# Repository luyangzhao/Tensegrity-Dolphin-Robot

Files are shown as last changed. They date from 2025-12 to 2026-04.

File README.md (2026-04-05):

# Tensegrity Dolphin Robot

Open-source design files for an **untethered bio-inspired robotic dolphin** with a **tensegrity-based, multi-flexibility tail** for efficient aquatic locomotion. This repository provides the mechanical, electronic, and software resources needed to understand, reproduce, and extend the robotic system presented in our RoboSoft 2025 paper.

---

### **🎥 Dolphin Demonstration Video**  
Please watch the robotic dolphin in action.

Dolphin Video (https://www.youtube.com/watch?v=avUUYTJ178g)

---
## Overview

The Tensegrity Dolphin Robot features a **hybrid rigid–soft architecture**:
- A rigid, waterproof head module housing electronics, actuation, and power.
- A flexible tensegrity tail skeleton enabling distributed compliance.
- A molded silicone tail skin provides smooth hydrodynamic surfaces.
- Modular connectors allow rapid tail replacement and reconfiguration.

By varying the internal tail skeleton geometry, the robot can achieve different flexibility profiles and swimming performance, enabling systematic studies of morphology–locomotion trade-offs.

---

## Repository Structure

```
Tensegrity-Dolphin-Robot/
├── CAD/          # Mechanical design files (head, tail, molds, connectors)
├── PCB/          # Electronics design files
├── Firmware/     # Embedded firmware (ESP32)
├── Software/     # Control code
├── assets/       # Images and media
├── LICENSE 
└── README.md
```
---

## Reference

This repository accompanies the paper:

 Luyang Zhao, Yitao Jiang, Chun-Yi She, Mingi Jeong, Haibo Dong, Alberto Quattrini Li, Muhao Chen, and Devin Balkcom., 2025. An Untethered Bioinspired Robotic Tensegrity Dolphin with Multi-Flexibility Design for Aquatic Locomotion. In *2025 IEEE 8th International Conference on Soft Robotics (RoboSoft)* (pp. 1-7). IEEE

Paper link:  
https://ieeexplore.ieee.org/document/11020959

If you use this repository in your research, please cite the above paper.

---

## Fabrication and Reproduction

This repository provides the design files and code necessary to reproduce the robotic system at a system level. Detailed fabrication procedures, material choices, and experimental setup are described in the accompanying paper.

In brief, reproduction involves:
1. Fabrication of the rigid head components and tensegrity tail skeleton
2. Molding of the silicone tail using the provided mold designs
3. Assembly of the actuation system and connectors
4. Integration of electronics and firmware
5. Waterproofing, tuning, and aquatic testing

Readers are encouraged to refer to the paper for detailed descriptions of materials, dimensions, and experimental protocols.

---

## Waterproofing Considerations

Waterproofing is a critical aspect of the robotic system and requires careful mechanical and material design. Based on our implementation, the key considerations include:

1. **Shaft sealing**  
   Proper sealing of rotating shafts is the primary and most critical waterproofing measure. Inadequate shaft sealing cannot be compensated for by external coatings or adhesives.

2. **Silicone-based sealing and bonding**  
   Silicone glue and sealants are used to seal housing interfaces, forming the system-level waterproof barrier.

3. **Water-resistant fabrication materials**  
   Waterproof or water-resistant printing materials (e.g., resin-based prints) help reduce water ingress but should be considered a supporting measure rather than a standalone solution.

Successful waterproofing requires the **combined use** of all three approaches rather than reliance on any single method.

---

## 📬 Contact

For questions, collaboration, or reproducibility assistance:

📧 **Luyang Zhao** — [luyangz@clemson.edu](mailto:luyangz@clemson.edu)  
📧 **Yitao Jiang** — [yitao.jiang.gr@dartmouth.edu](mailto:yitao.jiang.gr@dartmouth.edu)

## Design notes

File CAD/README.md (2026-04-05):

# CAD – Mechanical Design Files

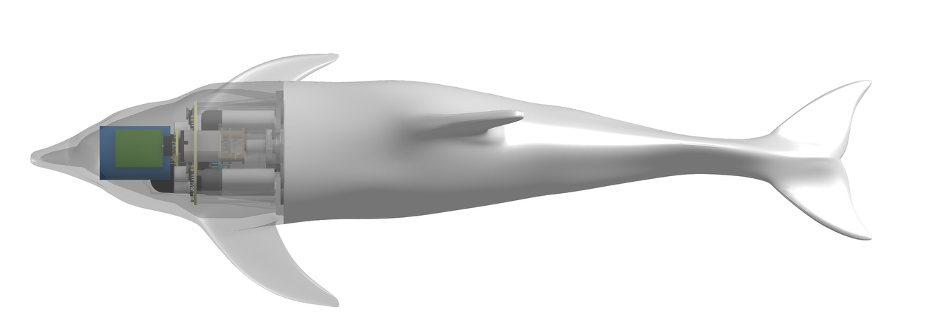
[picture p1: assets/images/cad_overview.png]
Mechanical overview of the dolphin robot showing the rigid head and tensegrity tail backbone.


This directory contains all mechanical CAD files for the **Tensegrity Dolphin Robot**, including rigid structural components, flexible tail structures, silicone molding tools, and modular connectors. The mechanical design follows a **hybrid rigid–soft architecture**:
- A rigid, waterproof head houses all electronics, actuation, and power components.
- A compliant tail enables efficient aquatic locomotion through distributed flexibility.
- Modular connectors allow rapid assembly, disassembly, and tail replacement.

---

## Directory Structure

```
CAD/
├── head/
├── tensegrity_tail/
├── silicone_tail_molding/
├── connectors/
```

---

## Subdirectories

### 1. `head/`
Rigid structural components form the waterproof head enclosure, includes:
- Outer shell and internal mounting frames  
- Motor, pulley, and cable-routing mounts  
- Battery, PCB, and wireless charging coil fixtures  
- Sealing interfaces and fastening features  

These components are designed to be fabricated via **3D printing or CNC machining** and assembled to form a pressure-resistant electronics compartment.

---

### 2. `tensegrity_tail/`
Internal flexible backbone defining the tail’s deformation behavior, includes:
- Fish-bone–inspired rigid ribs  
- Interconnecting elements and spacers  
- Cable routing guides and anchor points  

This structure provides **distributed compliance** and enables smooth bending under cable-driven actuation.

---

### 3. `silicone_tail_molding/`
Mold designs used to fabricate the soft silicone tail skin, includes:
- Multi-part molds for the outer tail geometry  
- Internal buoyancy chamber molds  
- Alignment, venting, and demolding features  

The molded silicone tail provides continuous curvature, tunable stiffness, and passive compliance for efficient swimming.

---

### 4. `connectors/`
Modular interfaces between the rigid head and the flexible tail, includes:
- Magnetic coupling components  
- Mechanical alignment and load-transfer features  

These connectors enable **rapid tail replacement and maintenance** without disassembling the head module.

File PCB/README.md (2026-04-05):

# **PCB Design** 

## 🔗 Access the PCB Design  
The full **schematic, layout, and fabrication files** for the PCB are available in this directory. Please use EasyEDA (LCEDA) to open **ProPrj_Dolphin 3D.epro** for the source. You can also directly use the Gerber, BOM, and CPL files to produce the board.

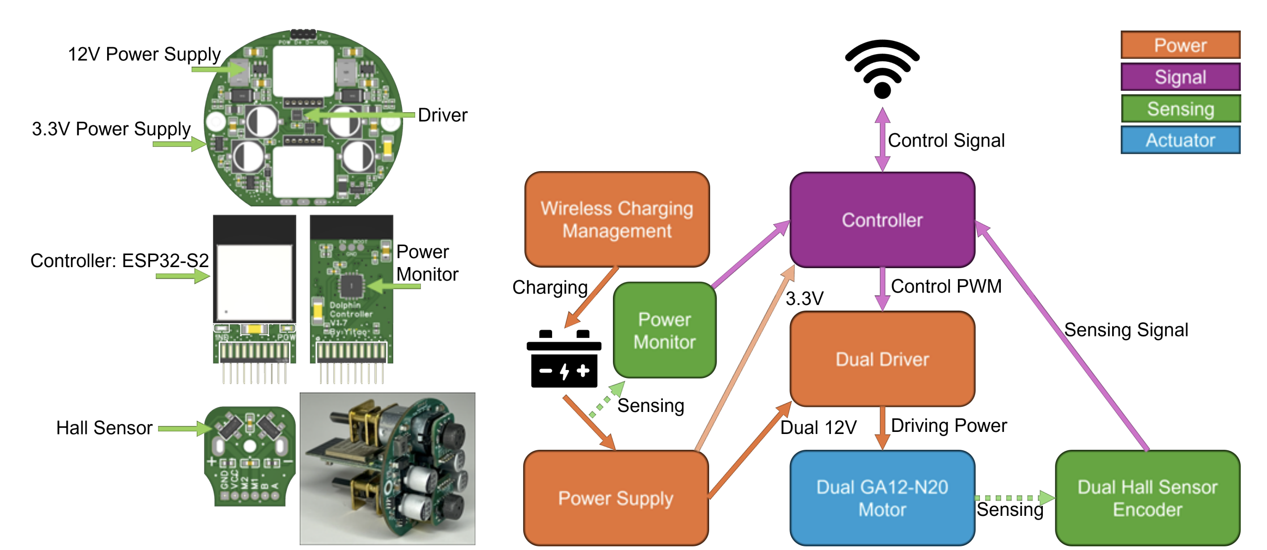
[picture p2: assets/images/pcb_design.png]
SoftSnap 3-in-1 Motor Module PCB
  

## 🛠️ Manufacture of this PCB
Recommend using **JLCPCB for production**.

Manufacturing parameters:  
1️⃣ **Main Board** – Use a 1 mm 4-layer board. Others can be default.  
2️⃣ **Controller** – Use a 0.8 mm 4-layer board. Others can be default.  
3️⃣ **Encoder** – Use a 1 mm 2-layer board. Others can be default.  

## 🛍️ Other parts for assembly the robot
You will need these components to build this Dolphin robot. If the link has expired, you can find an equivalent.  

1️⃣ **1.27x10x2p Male Pin Connector** – You need to solder the connector vertically to the Main Board as shown in the `pcb_design` figure.  
2️⃣ **702025 Li-Po Battery 250 mAh** – You need 2 batteries for one robot. [Taobao Link](https://item.taobao.com/item.htm?_u=fb6lncqb37e&id=707886319580&skuId=5171695959474)  
3️⃣ **5F/5.5V 21x10x27mm 16mm-pin Capacitor** – A smaller capacitor may also work, but this is perfectly fit in size. [Tmall Link](https://detail.tmall.com/item.htm?_u=fb6lncq1c6a&id=641504092942&skuId=4790094927334)  
4️⃣ **HK015T.1 Power Switch Chip** – This part is not in the JLCPCB library, so you may need to purchase it yourself. [Taobao Link](https://item.taobao.com/item.htm?_u=fb6lncq935a&id=675015766647&skuId=4893699864706)  
5️⃣ **Tactile switch 4x4x3.5** – This part will be used to control the power of the robot. [Taobao Link](https://item.taobao.com/item.htm?_u=fb6lncq47bf&id=578313422043&skuId=3994993738973)  
6️⃣ **5W receiving module (square 23x30 coil) + 10W transmitting module** – This part is for wireless charging. [Taobao Link](https://item.taobao.com/item.htm?_u=fb6lncq9349&id=681481042391&skuId=5051612254394)  
7️⃣ **Shaft Seal 5x13x5** – This part is for wireless charging. [Taobao Link](https://item.taobao.com/item.htm?_u=fb6lncq98e2&id=652255362545&skuId=4713539808324)  
8️⃣ **Encoder Magnet** – We are using a Radial 6-pole. If you can't find it, other poles may also work. [Taobao Link](https://item.taobao.com/item.htm?_u=fb6lncq2191&id=539394627100)  
9️⃣ **GA12-N20 Motor with rear shaft** – We are using 1:150 gear ratio, 12V, 200RPM (no load). Since we need a lot of this motor, we ordered it from this vendor. You may find other equivalents for a small quantity. [Taobao Link](https://shop108869903.taobao.com/?spm=pc_detail.30350276.shop_block.dshopinfo.2fe07dd6G8NZ3C)  
🔟 **M1.7*6 Self-Tapping Screws** – Use this screw to connect Main Board with 3D printed inner structure. [Tmall Link](https://detail.tmall.com/item.htm?_u=fb6lncqd00d&id=601243288882&skuId=5653049345641)  
1️⃣1️⃣ **M1.6*3 Screws** – Use this screw to connect GA12-N20 Motor with 3D printed inner structure. [Tmall Link](https://detail.tmall.com/item.htm?_u=fb6lncqb704&id=601243200968&skuId=5945136077418)  
1️⃣2️⃣ Wires are needed for assembly, recommend 22AWG or thicker for the power cord. The switch wire can be thin.

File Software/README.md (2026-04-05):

# Software – High-Level Control

This directory contains **high-level control and interaction software** for the **Tensegrity Dolphin Robot**. The software runs on an external computer and communicates wirelessly with the onboard firmware to command tail actuation and support basic experimentation.

---

## Contents

- `Control_Program_Dolphin.ipynb`  
  A Jupyter Notebook providing a high-level control interface for commanding the two tail motors to generate **undulatory swimming motions**.

The notebook is intended for demonstration, testing, and exploratory control, rather than optimized autonomous operation.

---

## Notes

- The software communicates with the embedded firmware provided in `firmware/`.
- Control parameters and motion patterns may require tuning depending on the tail configuration and materials.

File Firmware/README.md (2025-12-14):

# Firmware – Embedded Control

This directory contains the **embedded firmware** used to operate the **Tensegrity Dolphin Robot**.

The firmware runs on an onboard microcontroller and is responsible for low-level motor actuation, communication, and system management for untethered aquatic operation.

---

## Overview

The firmware supports:
- Cable-driven motor control for tail actuation
- Wireless communication for command and monitoring
- Basic system management for untethered operation

The firmware is designed to interface directly with the PCB referenced in `PCB/` and the mechanical components defined in `CAD/`.

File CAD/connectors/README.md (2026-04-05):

# Connectors – Tail–Head Interface

This directory contains CAD files for the **connector components** that interface the tensegrity tail skeleton with the rigid head module.

## Files

- `Tail_Connector.stl`  
  Connector component used to mechanically interface the tail skeleton with the head module. This part provides alignment and load transfer between the rigid head and the flexible tail.

## Notes

- The connector is compatible with all tail skeleton variants.

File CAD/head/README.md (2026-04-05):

- `Head.stl`  
  Outer head shell forming the hydrodynamic exterior and primary waterproof barrier. This part should be printed using **resin or other waterproof materials**.

- `Head_Inner.stl`  
  Internal structural frame for mounting motors, magnets, batteries, and electronics. This part does not require waterproof material and can be fabricated using standard 3D printing materials.

- `Winch.stl`  
  Winch component used to wind and release the actuation string driven by the motor.

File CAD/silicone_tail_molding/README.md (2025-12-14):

# Silicone Tail Molding – CAD Files

This directory contains CAD files related to the **fabrication of the soft silicone tail**, including molding tools and reference geometry.

---

## Files Overview

### Reference Geometry (Not for Printing)

- `silicone tail final shape (no need to print).stl`  
  Final outer geometry of the silicone tail after molding.  
  This file is provided **for reference and visualization only** and **should not be printed**.  
  It represents the expected final shape of the molded silicone tail.

---

### Molding Components (Used for Fabrication)

The following files are used to fabricate the silicone tail via molding:

- `Mold Outer A.stl`  
  One half of the outer mold defining the external surface of the silicone tail.

- `Mold Outer B.stl`  
  The complementary half of the outer mold.  
  Together with `Mold Outer A.stl`, it forms the complete outer mold cavity.

- `Mold Inner.stl`  
  Inner mold insert used to form internal features of the silicone tail, such as internal cavities or buoyancy chambers.

---

## Notes

- Only the **mold components and inserts** should be fabricated (e.g., via 3D printing).
- The final silicone tail is produced by casting silicone into the assembled mold.

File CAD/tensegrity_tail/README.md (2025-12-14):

# Tensegrity Tail – Skeleton Variants

This directory contains **six tensegrity tail skeleton variants** corresponding to the designs evaluated in the paper.  
All variants share the same overall geometry and interface to the head module, but differ in **rib height ratio (h₁:h₂)** and **structural thickness ratio**, resulting in different tail flexibility and swimming performance.

---

## Skeleton Variants

The following STL files correspond to the skeleton types reported in the paper:

| Skeleton Type | h₁:h₂ | Thickness Ratio | STL File |
|---|---|---|---|
| Type 1 | 1:1 | 1:1 | `Type1_h1-1_thick1-1.stl` |
| Type 2 | 1:1 | 2:1 | `Type2_h1-1_thick2-1.stl` |
| Type 3 | 1:1 | 3:1 | `Type3_h1-1_thick3-1.stl` |
| Type 4 | 1:2 | 1:1 | `Type4_h1-2_thick1-1.stl` |
| Type 5 | 1:2 | 2:1 | `Type5_h1-2_thick2-1.stl` |
| Type 6 | 1:2 | 3:1 | `Type6_h1-2_thick3-1.stl` |

---

## Usage Notes

- All skeleton variants are **mechanically compatible** with the same head module, connectors, and actuation system.
- Skeletons can be swapped without modifying electronics or control software.
- Changing the skeleton alters tail flexibility, bending amplitude, swimming speed, and energy efficiency.

Type 4 (`Type4_h1-2_thick1-1.stl`) has fastest swimming speed and lowest cost of transport.

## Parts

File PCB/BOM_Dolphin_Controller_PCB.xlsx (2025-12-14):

No. | Quantity | Device | Designator | Footprint | Value | Manufacturer Part | Manufacturer | Supplier Part | Supplier | JLCPCB Part Class
1 | 2 | CL31A107MQHNNNE | C6,C19 | C1206 | 100uF | CL31A107MQHNNNE | SAMSUNG(三星) | C15008 | LCSC | Basic Part
2 | 1 | CL21A226MAQNNNE | C7 | C0805 | 22uF | CL21A226MAQNNNE | SAMSUNG(三星) | C45783 | LCSC | Basic Part
3 | 2 | CL05B104KB54PNC | C8,C17 | C0402 | 100nF | CL05B104KB54PNC | SAMSUNG(三星) | C307331 | LCSC | Basic Part
4 | 2 | CL05A105KA5NQNC | C16,C18 | C0402 | 1uF | CL05A105KA5NQNC | SAMSUNG(三星) | C52923 | LCSC | Basic Part
5 | 1 | KH-1.27PH180-2X10P-L7.2 | H1 | KH-1.27PH180-2X10P-L7.2 夹板 |  | KH-1.27PH180-2X10P-L7.2 | kinghelm(金航标) | C2938414 | LCSC | 扩展库
6 | 1 | KT-0603R | LED1 | LED0603-RD |  | KT-0603R | KENTO | C2286 | LCSC | Basic Part
7 | 1 | KT-0603W | LED2 | LED0603-RD |  | KT-0603W | KENTO | C2290 | LCSC | Basic Part
8 | 3 | 0402WGF1001TCE | R3,R8,R9 | R0402 | 1kΩ | 0402WGF1001TCE | UNI-ROYAL(厚声) | C11702 | LCSC | Basic Part
9 | 2 | Test-Point | TP1,TP2 | test-point-0.5mm
10 | 1 | ESP32-S2-MINI-2-N4 | U1 | WIFI-SMD_ESP32-MINI-1-N4 | 2.4GHz | ESP32-S2-MINI-2-N4 | ESPRESSIF(乐鑫) | C3013906 | LCSC | Extended Part
11 | 1 | INA3221AIRGVR | U7 | QFN-16_L4.0-W4.0-P0.65-TL-EP2.2 |  | INA3221AIRGVR | TI(德州仪器) | C181255 | LCSC | 扩展库

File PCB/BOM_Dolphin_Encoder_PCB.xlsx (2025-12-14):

No. | Quantity | Device | Designator | Footprint | Value | Manufacturer Part | Manufacturer | Supplier Part | Supplier | JLCPCB Part Class
1 | 1 | CL05A105KA5NQNC | C1 | C0402 | 1uF | CL05A105KA5NQNC | SAMSUNG(三星) | C52923 | LCSC | Basic Part
2 | 1 | CL05B104KB54PNC | C2 | C0402 | 100nF | CL05B104KB54PNC | SAMSUNG(三星) | C307331 | LCSC | Basic Part
3 | 2 | 0402WGF2201TCE | R1,R2 | R0402 | 2.2kΩ | 0402WGF2201TCE | UNI-ROYAL(厚声) | C25879 | LCSC | Basic Part
4 | 2 | DRV5013ADQDBZR | U1,U2 | SOT-23-3_L2.9-W1.3-P1.90-LS2.4-BR |  | DRV5013ADQDBZR | TI(德州仪器) | C575585 | LCSC | Extended Part
5 | 1 | PZ127-1-06-Z | U3 | HDR-TH_6P-P1.27-V-M |  | PZ127-1-06-Z | HCTL(华灿天禄) | C5372829 | LCSC | 扩展库

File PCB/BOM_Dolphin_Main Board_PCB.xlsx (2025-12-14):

No. | Quantity | Device | Designator | Footprint | Value | Manufacturer Part | Manufacturer | Supplier Part | Supplier | JLCPCB Part Class
1 | 4 | 126RV0010 | C1,C17,C18,C19 | CAP-SMD_BD6.3-L6.6-W6.6-FD | 470uF | 126RV0010 | KNSCHA(科尼盛) | C5354997 | LCSC | Extended Part
2 | 2 | CL05A105KA5NQNC | C2,C3 | C0402 | 1uF | CL05A105KA5NQNC | SAMSUNG(三星) | C52923 | LCSC | Basic Part
3 | 5 | CL05B104KB54PNC | C9,C10,C38,C43,C44 | C0402 | 100nF | CL05B104KB54PNC | SAMSUNG(三星) | C307331 | LCSC | Basic Part
4 | 1 | CL31A107MQHNNNE | C29 | C1206 | 100uF | CL31A107MQHNNNE | SAMSUNG(三星) | C15008 | LCSC | Basic Part
5 | 6 | CL21A226MAQNNNE | C31,C35,C39,C40,C41,C42 | C0805 | 22uF | CL21A226MAQNNNE | SAMSUNG(三星) | C45783 | LCSC | Basic Part
6 | 1 | CL05A106MQ5NUNC | C45 | C0402 | 10uF | CL05A106MQ5NUNC | SAMSUNG(三星) | C15525 | LCSC | Basic Part
7 | 2 | PM127-1-06-4.3-G0 | CN2,CN3 | HDR-TH_6P-P1.27-V-F |  | PM127-1-06-4.3-G0 | HCTL(华灿天禄) | C5447364 | LCSC | Extended Part
8 | 2 | SS54_C22452 | D4,D5 | SMA_L4.4-W2.8-LS5.4-R-RD |  | SS54 | MDD(辰达半导体) | C22452 | LCSC | Basic Part
9 | 1 | 1N5819WS_C191023 | D6 | SOD-323_L1.8-W1.3-LS2.5-RD |  | 1N5819WS | Hottech(合科泰) | C191023 | LCSC | 基础库
10 | 1 | PZ127V-11-04-H25 | H3 | HDR-TH_4P-P1.27-V-M |  | PZ127V-11-04-H25 | XFCN(兴飞) | C962328 | LCSC | 扩展库
11 | 2 | SMNR4030-6R8MT | L2,L3 | IND-SMD_L4.0-W4.0_FNR4012S | 6.8uH | SMNR4030-6R8MT | SXN(顺翔诺) | C5307592 | LCSC | Extended Part
12 | 1 | AO3401A_C15127 | Q1 | SOT-23_L2.9-W1.3-P1.90-LS2.4-BR |  | AO3401A | AOS | C15127 | LCSC | 基础库
13 | 3 | 0402WGF2003TCE | R12,R33,R34 | R0402 | 200kΩ | 0402WGF2003TCE | UNI-ROYAL(厚声) | C25764 | LCSC | Basic Part
14 | 1 | 0402WGF1001TCE | R15 | R0402 | 1kΩ | 0402WGF1001TCE | UNI-ROYAL(厚声) | C11702 | LCSC | 基础库
15 | 2 | RL0805FR-070R04L | R17,R27 | R0805 | 40mΩ | RL0805FR-070R04L | YAGEO(国巨) | C326963 | LCSC | 扩展库
16 | 6 | 0402WGF100KTCE | R21,R22,R28,R29,R30,R31 | R0402 | 1Ω | 0402WGF100KTCE | UNI-ROYAL(厚声) | C25086 | LCSC | Extended Part
17 | 2 | 0402WGF1743TCE | R23,R25 | R0402 | 174kΩ | 0402WGF1743TCE | UNI-ROYAL(厚声) | C26994 | LCSC | Extended Part
18 | 2 | 0402WGF1002TCE | R24,R26 | R0402 | 10kΩ | 0402WGF1002TCE | UNI-ROYAL(厚声) | C25744 | LCSC | Basic Part
19 | 1 | HoLR1206-1W-20mR-1%-75ppm | R32 | R1206 | 20mΩ | HoLR1206-1W-20mR-1%-75ppm | Milliohm(毫欧) | C601099 | LCSC | 扩展库
20 | 1 | RT9013-33GB | U1 | SOT-23-5_L3.0-W1.7-P0.95-LS2.8-BL |  | RT9013-33GB | RICHTEK(立锜) | C47773 | LCSC | Extended Part
21 | 2 | DRV8837DSGR | U4,U5 | WSON-8_L2.0-W2.0-P0.50-TL-EP |  | DRV8837DSGR | TI(德州仪器) | C39159 | LCSC | Extended Part
22 | 2 | MT3608L | U8,U9 | SOT-23-6_L2.9-W1.7-P0.95-LS2.8-BL |  | MT3608L | 西安航天民芯 | C2932326 | LCSC | Extended Part
23 | 1 | KH-1.27FH-2X10P-H4.3-SMT | U10 | CONN-SMD_20P-P1.27_KINGHELM_KH-1.27FH-2X10P-H4.3-SMT |  | KH-1.27FH-2X10P-H4.3-SMT | kinghelm(金航标) | C2938399 | LCSC | 扩展库
24 | 1 | HOKEC 0339D | U13 | SOT-23-6_L2.9-W1.6-P0.95-LS2.8-BL

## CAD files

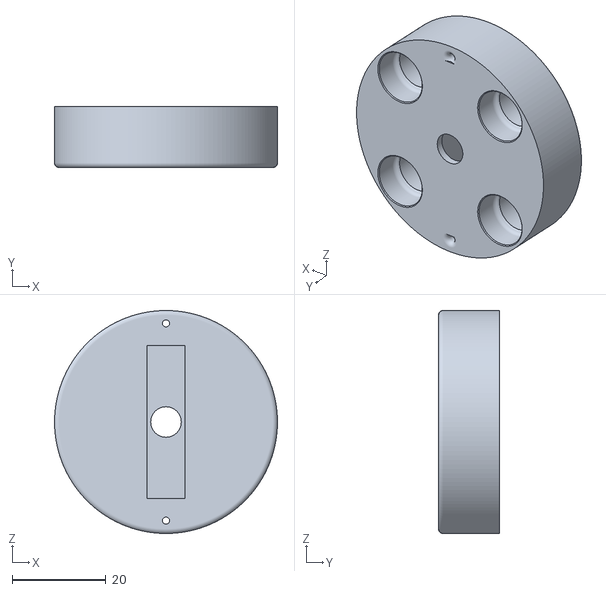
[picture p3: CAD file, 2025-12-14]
CAD/connectors/Tail Connector.stl
47.5 x 13.0 x 47.5

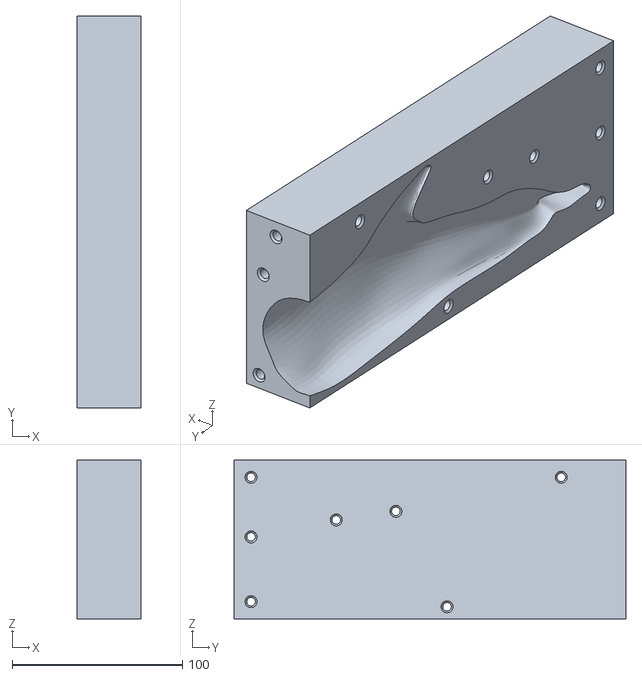
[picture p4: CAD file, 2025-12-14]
CAD/silicone_tail_molding/Mold Outer B.stl
37.5 x 230.0 x 93.0

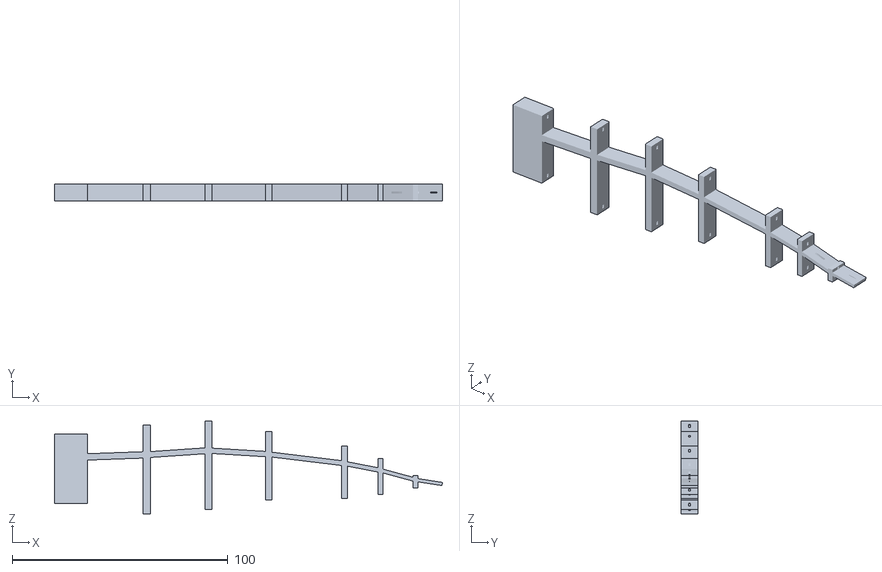
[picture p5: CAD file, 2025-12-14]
CAD/tensegrity_tail/Type5_h1-2_thick2-1.stl
179.9 x 8.00 x 43.0

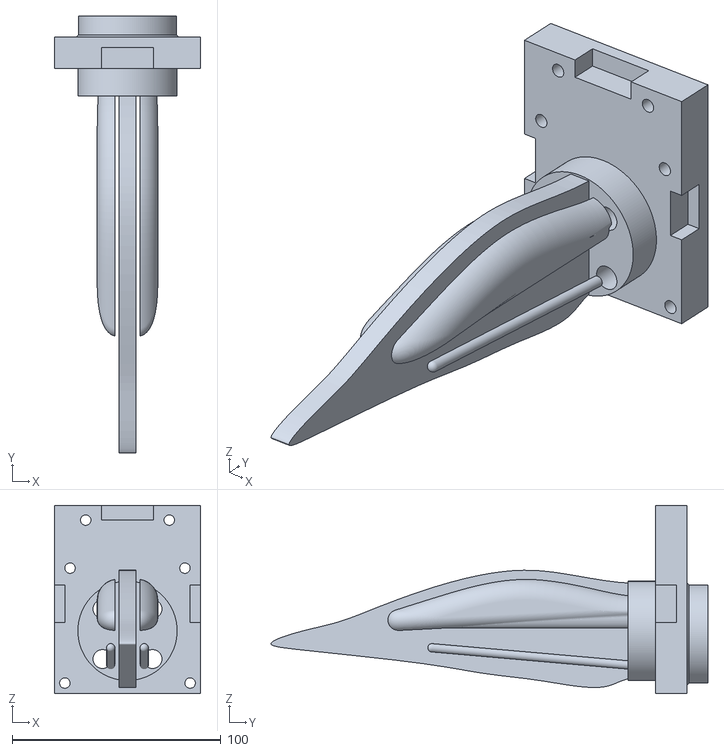
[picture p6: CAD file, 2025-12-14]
CAD/silicone_tail_molding/Mold Inner.stl
70.0 x 209.1 x 90.0

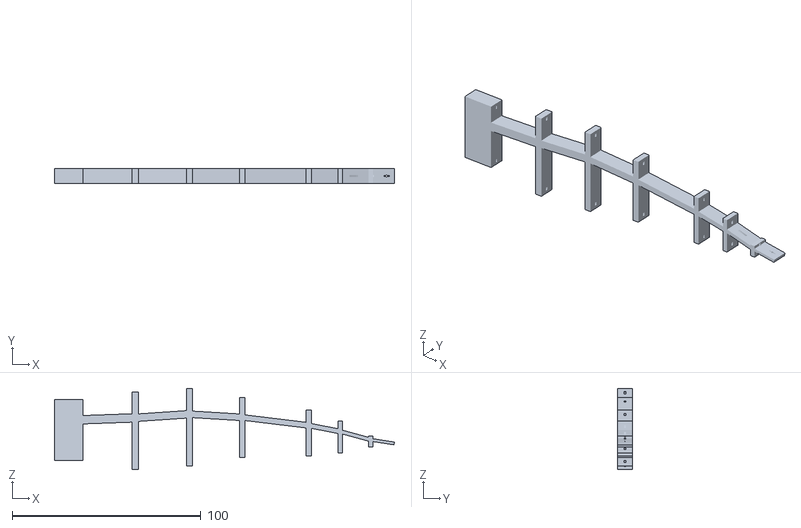
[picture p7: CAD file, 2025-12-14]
CAD/tensegrity_tail/Type6_h1-2_thick3-1.stl
179.9 x 8.00 x 43.0

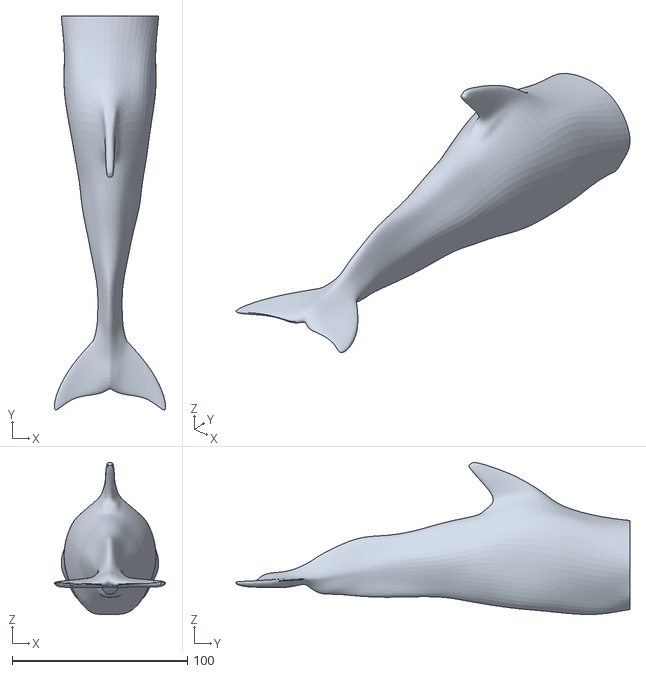
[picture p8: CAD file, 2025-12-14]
CAD/silicone_tail_molding/silicone tail final shape (no need to print).stl
63.3 x 224.7 x 86.7

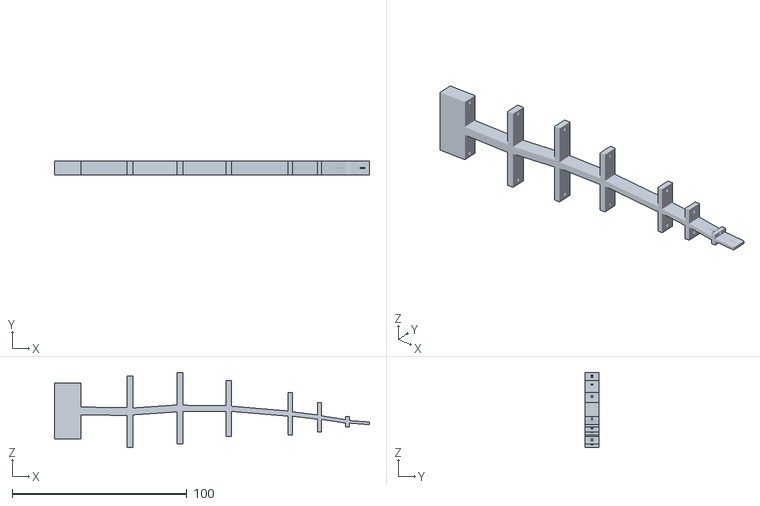
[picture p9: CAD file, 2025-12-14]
CAD/tensegrity_tail/Type3_h1-1_thick3-1.stl
180.3 x 8.00 x 43.0

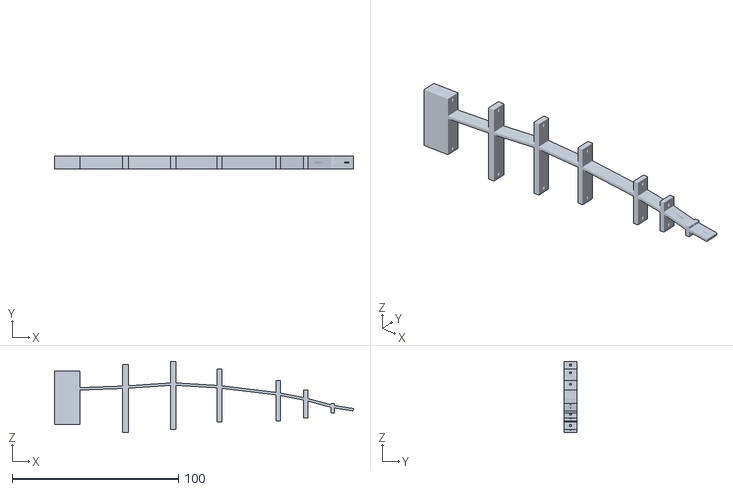
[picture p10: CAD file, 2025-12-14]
CAD/tensegrity_tail/Type4_h1-2_thick1-1.stl
179.9 x 8.00 x 43.0

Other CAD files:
CAD/silicone_tail_molding/Mold Outer A.stl
CAD/tensegrity_tail/Type2_h1-1_thick2-1.stl
CAD/tensegrity_tail/Type1_h1-1_thick1-1.stl

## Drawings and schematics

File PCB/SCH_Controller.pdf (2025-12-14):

IO36 32 IO37 33 IO38 34 IO39 35 IO40 36 IO41 37 IO42 38 TXD0 39 RXD0 40 IO45 41 GND 42 GND 43 IO46 44 EN 45 GND 46 GND 47 GND 48 GND 49 GND 50 GND 51 GND 52 GND 53 GND 54 GND 55 GND 56 GND 57 GND 58 GND 59 GND 60 GND 61 GND 62 GND 63 GND 64 GND 65

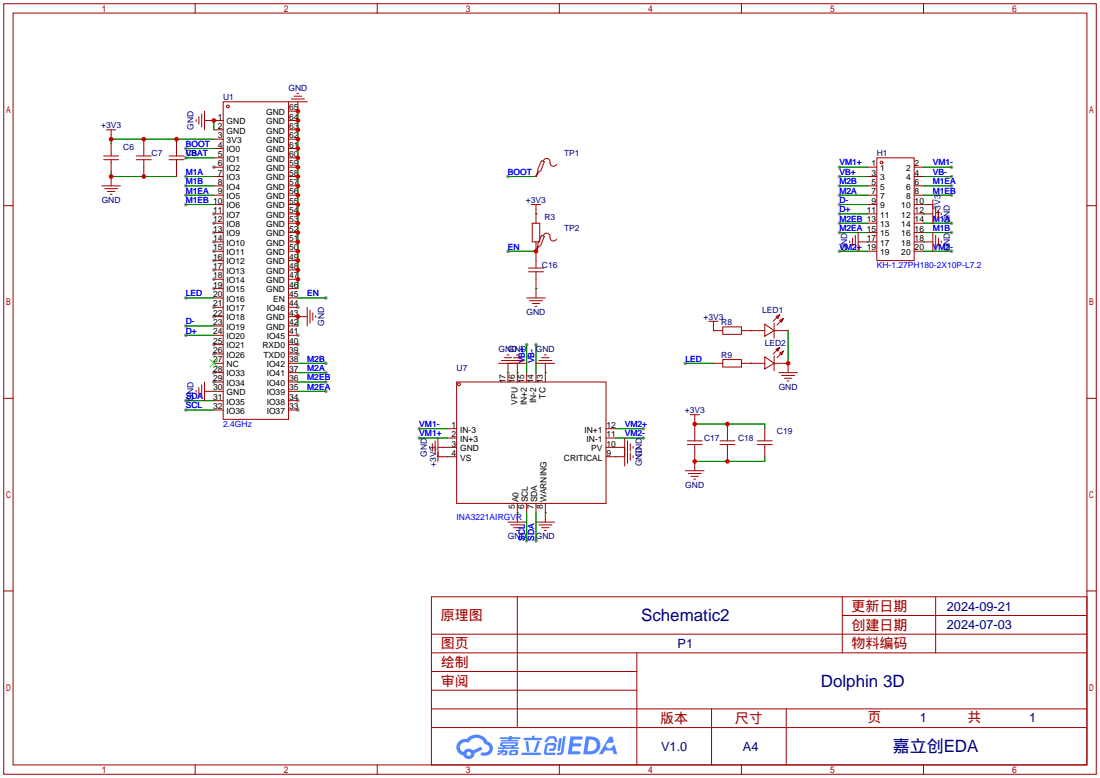
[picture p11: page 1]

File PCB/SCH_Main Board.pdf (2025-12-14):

# M1EA GND+3V³

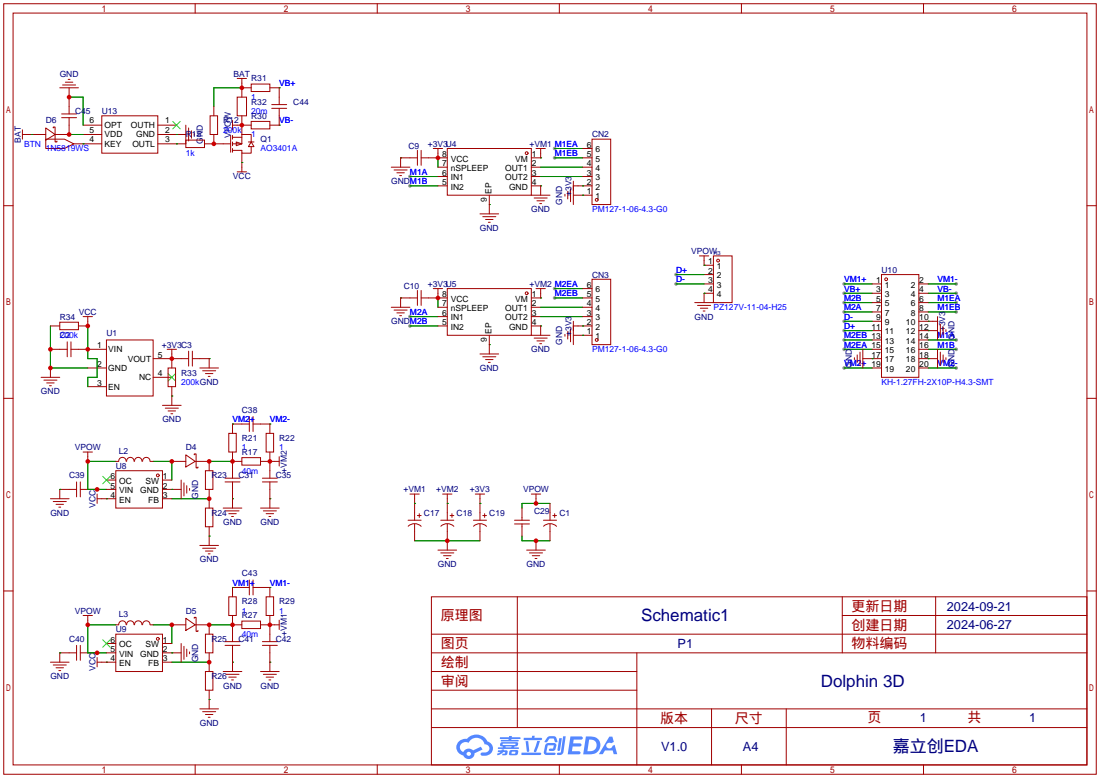
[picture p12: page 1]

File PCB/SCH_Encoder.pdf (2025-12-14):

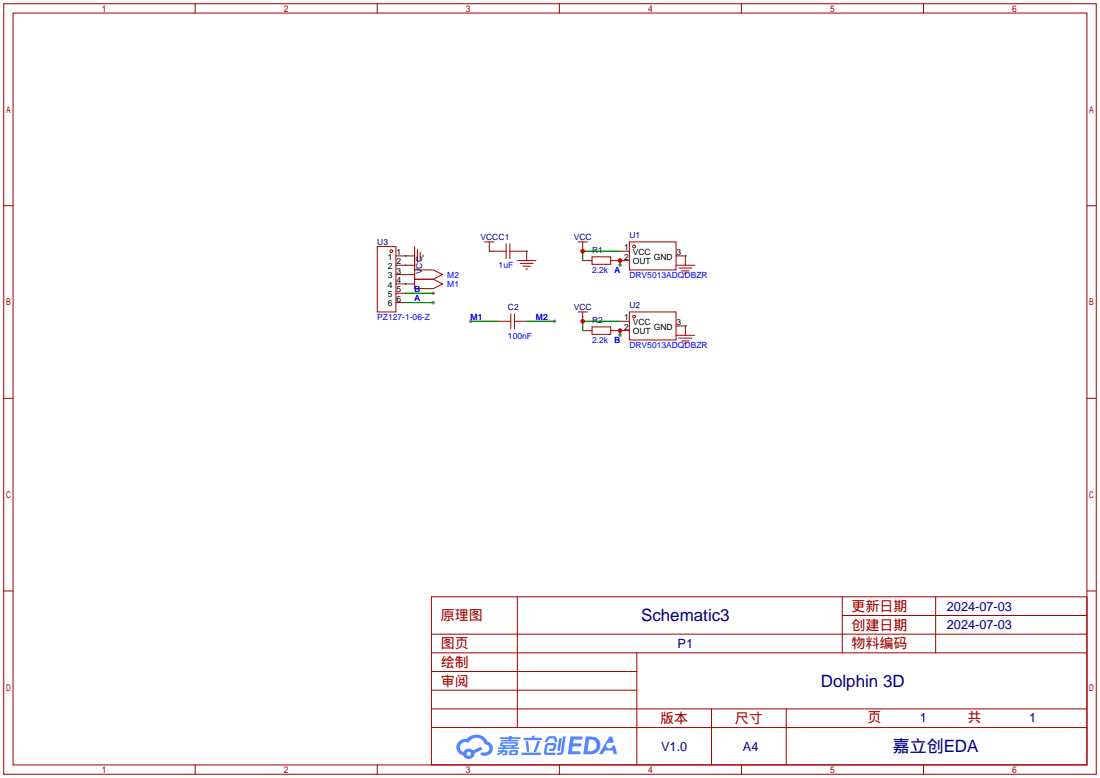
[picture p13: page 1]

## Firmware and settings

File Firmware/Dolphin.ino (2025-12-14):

#include <WiFi.h>
#include <ArduinoOTA.h>
#include <Wire.h>
#include <PID_v1.h>
#include <ArduinoJson.h>
#include <vector>
#include <math.h>

#define tolerance 30

#define M1A 3
#define M1B 4
#define M1EA 5
#define M1EB 6
#define M2A 41
#define M2B 42
#define M2EA 39
#define M2EB 40
#define LED 16
#define VBAT 1
#define SDA 35
#define SCL 36

#define INA3221_ADDR 0x40

// INA3221寄存器地址
#define INA3221_CONFIG_REG 0x00
#define INA3221_SHUNT_VOLTAGE_CH1 0x01
#define INA3221_BUS_VOLTAGE_CH1 0x02
#define INA3221_SHUNT_VOLTAGE_CH2 0x03
#define INA3221_BUS_VOLTAGE_CH2 0x04
#define INA3221_SHUNT_VOLTAGE_CH3 0x05
#define INA3221_BUS_VOLTAGE_CH3 0x06

// 给功率计算使用的变量
#define record_number 1200
volatile int32_t lastTick_ms = 0;
struct Power {
  uint16_t VBUS_BUS;
  uint16_t VBUS_TOP;
  uint16_t VBUS_BOT;
  uint16_t VSHUNT_BUS;
  uint16_t VSHUNT_TOP;
  uint16_t VSHUNT_BOT;
};
static volatile Power PowerData[record_number];
volatile uint32_t power_counter = 0;

// PID参数
double M1_Kp = 0.1, M1_Ki = 0.01, M1_Kd = 0;
double M2_Kp = 0.1, M2_Ki = 0.01, M2_Kd = 0;
double M1_input, M1_output, M1_setpoint;
double M2_input, M2_output, M2_setpoint;
PID M1_PID(&M1_input, &M1_output, &M1_setpoint, M1_Kp, M1_Ki, M1_Kd, DIRECT);
PID M2_PID(&M2_input, &M2_output, &M2_setpoint, M2_Kp, M2_Ki, M2_Kd, DIRECT);

double M1_velocity_Kp = 0.1, M1_velocity_Ki = 0.01, M1_velocity_Kd = 0;
double M2_velocity_Kp = 0.1, M2_velocity_Ki = 0.01, M2_velocity_Kd = 0;
double M1_velocity_input, M1_velocity_output, M1_velocity_setpoint;
double M2_velocity_input, M2_velocity_output, M2_velocity_setpoint;
PID M1_velocity_PID(&M1_velocity_input, &M1_velocity_output, &M1_velocity_setpoint, M1_velocity_Kp, M1_velocity_Ki, M1_velocity_Kd, DIRECT);
PID M2_velocity_PID(&M2_velocity_input, &M2_velocity_output, &M2_velocity_setpoint, M2_velocity_Kp, M2_velocity_Ki, M2_velocity_Kd, DIRECT);

// 轨迹参数
struct Segment {
  double params[6];
};
std::vector<Segment> M1_trajectoryParameters;
std::vector<Segment> M2_trajectoryParameters;

// 简单模式传参
struct SimpleParm {
  uint8_t power;
  int32_t target;
};

// 时间变量
int32_t startTime = -2147483648;
int32_t totalTime = 0;

static const char *ssid = "BotTest";
static const char *password = "123456789";

// Set web server port number to 80
WiFiServer server(80);
// Variable to store the HTTP request
String header;

volatile int32_t M1_target = 0;
volatile int32_t M1_current = 0;
volatile int32_t M1_error = 0;
volatile uint8_t M1_power = 0;
volatile int32_t M2_target = 0;
volatile int32_t M2_current = 0;
volatile int32_t M2_error = 0;
volatile uint8_t M2_power = 0;
volatile uint32_t pause_bot = 0;

volatile uint8_t M1_rec, M2_rec;

void motorControl() {
  if (pause_bot == 0) {
    // 电机1控制
    if (M1_velocity_output > 0) {
      ledcWrite(M1A, abs(M1_velocity_output));
      ledcWrite(M1B, 0);
    } else if (M1_velocity_output < 0) {
      ledcWrite(M1A, 0);
      ledcWrite(M1B, abs(M1_velocity_output));
    } else {
      ledcWrite(M1A, 0);
      ledcWrite(M1B, 0);
    }

    // 电机2控制
    if (M2_velocity_output > 0) {
      ledcWrite(M2A, abs(M2_velocity_output));
      ledcWrite(M2B, 0);
    } else if (M2_velocity_output < 0) {
      ledcWrite(M2A, 0);
      ledcWrite(M2B, abs(M2_velocity_output));
    } else {
      ledcWrite(M2A, 0);
      ledcWrite(M2B, 0);
    }
  } else {
    // 如果暂停，停止所有电机
    ledcWrite(M1A, 0);
    ledcWrite(M1B, 0);
    ledcWrite(M2A, 0);
    ledcWrite(M2B, 0);
  }
}

void motorSimple()
{
  if (M1_target - tolerance * 3 > M1_current && !pause_bot)
  {
    ledcWrite(M1A, M1_power);
    ledcWrite(M1B, 0);
  }
  else if (M1_target - tolerance * 2 > M1_current && !pause_bot)
  {
    ledcWrite(M1A, (M1_power - 20) / 10 + 20);
    ledcWrite(M1B, 0);
  }
  else if (M1_target - tolerance > M1_current && !pause_bot)
  {
    ledcWrite(M1A, (M1_power < 10) ? M1_power : 10);
    ledcWrite(M1B, 0);
  }
  else if (M1_target + tolerance * 3 < M1_current && !pause_bot)
  {
    ledcWrite(M1A, 0);
    ledcWrite(M1B, M1_power);
  }
  else if (M1_target - tolerance * 2 > M1_current && !pause_bot)
  {
    ledcWrite(M1A, 0);
    ledcWrite(M1B, (M1_power - 20) / 10 + 20);
  }
  else if (M1_target + tolerance < M1_current && !pause_bot)
  {
    ledcWrite(M1A, 0);
    ledcWrite(M1B, (M1_power < 10) ? M1_power : 10);
  }
  else
  {
    ledcWrite(M1A, 255);
    ledcWrite(M1B, 255);
  }

  if (M2_target - tolerance * 3 > M2_current && !pause_bot)
  {
    ledcWrite(M2A, M2_power);
    ledcWrite(M2B, 0);
  }
  else if (M2_target - tolerance * 2 > M2_current && !pause_bot)
  {
    ledcWrite(M2A, (M2_power - 20) / 10 + 20);
    ledcWrite(M2B, 0);
  }
  else if (M2_target - tolerance > M2_current && !pause_bot)
  {
    ledcWrite(M2A, (M2_power < 10) ? M2_power : 10);
    ledcWrite(M2B, 0);
  }
  else if (M2_target + tolerance * 3 < M2_current && !pause_bot)
  {
    ledcWrite(M2A, 0);
    ledcWrite(M2B, M2_power);
  }
  else if (M2_target + tolerance * 2 < M2_current && !pause_bot)
  {
    ledcWrite(M2A, 0);
    ledcWrite(M2B, (M2_power - 20) / 10 + 20);
  }
  else if (M2_target + tolerance < M2_current && !pause_bot)
  {
    ledcWrite(M2A, 0);
    ledcWrite(M2B, (M2_power < 10) ? M2_power : 10);
  }
  else
  {
    ledcWrite(M2A, 255);
    ledcWrite(M2B, 255);
  }
}

void IRAM_ATTR isr() {
  uint8_t M1_now = (digitalRead(M1EA) << 1) | digitalRead(M1EB);
  uint8_t M2_now = (digitalRead(M2EA) << 1) | digitalRead(M2EB);

  // 00,01,11,10
  // ++--++--=dolphin
  // --++--++=on the water
  if ((M1_rec == 0b00 && M1_now == 0b01) || (M1_rec == 0b01 && M1_now == 0b11) || (M1_rec == 0b11 && M1_now == 0b10) || (M1_rec == 0b10 && M1_now == 0b00))
    M1_current++;
  else if ((M1_rec == 0b10 && M1_now == 0b11) || (M1_rec == 0b11 && M1_now == 0b01) || (M1_rec == 0b01 && M1_now == 0b00) || (M1_rec == 0b00 && M1_now == 0b10))
    M1_current--;
  else if (M1_rec != M1_now)
    M1_error++;
  if ((M2_rec == 0b00 && M2_now == 0b01) || (M2_rec == 0b01 && M2_now == 0b11) || (M2_rec == 0b11 && M2_now == 0b10) || (M2_rec == 0b10 && M2_now == 0b00))
    M2_current++;
  else if ((M2_rec == 0b10 && M2_now == 0b11) || (M2_rec == 0b11 && M2_now == 0b01) || (M2_rec == 0b01 && M2_now == 0b00) || (M2_rec == 0b00 && M2_now == 0b10))
    M2_current--;
  else if (M2_rec != M2_now)
    M2_error++;

  M1_rec = M1_now;
  M2_rec = M2_now;
}

double segmentedFunction(int64_t t, const std::vector<Segment> &parameters) {
  if (parameters.size() == 0) {
    return 0;
  }
  if (totalTime == -1) {
    t %= (int32_t)parameters[parameters.size() - 1].params[0];
  }
  for (size_t i = 0; i < parameters.size(); i++) {
    if (t <= parameters[i].params[0]) {
      uint8_t functionType = (uint8_t)parameters[i].params[1];
      double a = parameters[i].params[2];
      double b = parameters[i].params[3];
      double c = parameters[i].params[4];
      double d = parameters[i].params[5];

      if (functionType == 0) { // 三次函数
        double t2 = t * t;
        double t3 = t2 * t;

        return a * t3 + b * t2 + c * t + d;
      } else if (functionType == 1) { // Sin函数
        return sin(a * t + b) * c + d;
      }
      else if (functionType == 2) { // 简易控制（直接控制power和位置）
        return NAN;
      }
      else {
        return 0;
      }
    }
  }

  // 如果 t 超出范围，返回最后一段函数在其终点的值
  size_t last = parameters.size() - 1;
  int64_t lastT = (int64_t)parameters[last].params[0];
  if ((uint8_t)parameters[last].params[1] == 0) {
    return parameters[last].params[2] * lastT * lastT * lastT + parameters[last].params[3] * lastT * lastT + parameters[last].params[4] * lastT + parameters[last].params[5];
  } else if ((uint8_t)parameters[last].params[1] == 1) {
    return sin(parameters[last].params[2] * lastT + parameters[last].params[3]) * parameters[last].params[4] + parameters[last].params[5];
  } else if ((uint8_t)parameters[last].params[1] == 2) {
    return NAN;
  }
  return 0;
}

SimpleParm simpleControl(int64_t t, const std::vector<Segment> &parameters) {
  SimpleParm simpleParm;
  simpleParm.power = 0;
  simpleParm.target = 0;

  if (parameters.size() == 0) {
    return simpleParm;
  }
  if (totalTime == -1) {
    t %= (int32_t)parameters[parameters.size() - 1].params[0];
  }
  for (size_t i = 0; i < parameters.size(); i++) {
    if (t <= parameters[i].params[0]) {
      uint8_t functionType = (uint8_t)parameters[i].params[1];
      double a = parameters[i].params[2]; // dummy
      double b = parameters[i].params[3]; // dummy
      double c = parameters[i].params[4]; // power
      double d = parameters[i].params[5]; // target
      int32_t power = (int32_t)c;
      // 缓启动，改善电流冲击
      if ((i == 0 && t <= 65) || (i > 0 && t - 65 < parameters[i - 1].params[0])) {
        power = power > 32 ? 32 : power;
      }
      else if ((i == 0 && t <= 105) || (i > 0 && t - 105 < parameters[i - 1].params[0])) {
        power = power > 64 ? 64 : power;
      }
      int32_t target = (int32_t)d;
      simpleParm.power = (uint8_t)power;
      simpleParm.target = target;
      return simpleParm;
    }
  }
  return simpleParm;
}

void parseTrajectoryJson(String json) {
  DynamicJsonDocument doc(8192);  // 根据预期的JSON大小调整容量

  DeserializationError error = deserializeJson(doc, json);
  if (error) {
    Serial.println("JSON解析失败");
    return;
  }

  totalTime = doc["totalTime"].as<int32_t>();

  M1_trajectoryParameters.clear();
  M2_trajectoryParameters.clear();

  JsonArray M1_segments = doc["M1_trajectory"];
  for (JsonArray segment : M1_segments) {
    Segment seg;
    for (int i = 0; i < 6 && i < segment.size(); i++) {
      seg.params[i] = segment[i].as<double>();
    }
    M1_trajectoryParameters.push_back(seg);
  }

  JsonArray M2_segments = doc["M2_trajectory"];
  for (JsonArray segment : M2_segments) {
    Segment seg;
    for (int i = 0; i < 6 && i < segment.size(); i++) {
      seg.params[i] = segment[i].as<double>();
    }
    M2_trajectoryParameters.push_back(seg);
  }
}

void parsePIDJson(String json) {
  DynamicJsonDocument doc(256);  // 根据预期的JSON大小调整容量

  DeserializationError error = deserializeJson(doc, json);
  if (error) {
    Serial.println("JSON解析失败");
    return;
  }

  M1_Kp = M2_Kp = doc["Kp"].as<double>();
  M1_Ki = M2_Ki = doc["Ki"].as<double>();
  M1_Kd = M2_Kd = doc["Kd"].as<double>();
  M1_velocity_Kp = M2_velocity_Kp = doc["vKp"].as<double>();
  M1_velocity_Ki = M2_velocity_Ki = doc["vKi"].as<double>();
  M1_velocity_Kd = M2_velocity_Kd = doc["vKd"].as<double>();
  M1_PID.SetTunings(M1_Kp, M1_Ki, M1_Kd);
  M2_PID.SetTunings(M2_Kp, M2_Ki, M2_Kd);
  M1_velocity_PID.SetTunings(M1_velocity_Kp, M1_velocity_Ki, M1_velocity_Kd);
  M2_velocity_PID.SetTunings(M2_velocity_Kp, M2_velocity_Ki, M2_velocity_Kd);
}

String urlDecode(String input) {
  String result = "";
  char c;
  int len = input.length();

  for (int i = 0; i < len; i++) {
    c = input.charAt(i);
    if (c == '+') {
      result += ' ';
    } else if (c == '%') {
      if (i + 2 < len) {
        int hex = 0;
        for (int j = 1; j <= 2; j++) {
          c = input.charAt(i + j);
          if (c >= '0' && c <= '9') {
            hex += (c - '0') * (j == 1 ? 16 : 1);
          } else if (c >= 'A' && c <= 'F') {
            hex += (c - 'A' + 10) * (j == 1 ? 16 : 1);
          } else if (c >= 'a' && c <= 'f') {
            hex += (c - 'a' + 10) * (j == 1 ? 16 : 1);
          }
        }
        result += char(hex);
        i += 2;
      }
    } else {
      result += c;
    }
  }

  return result;
}

float getBattery() {
  int32_t temp = 0;
  for (int32_t i = 0; i < 8; i++)
    temp += analogRead(VBAT);
  return (float)temp * 0.0000808068060588885f - 0.00308826876628743f;
}

String getPower() {
  String result = "";
  for (int i = 0; i < record_number; i++) {
    int index = (power_counter + i + 1) % record_number;
    char hexStr[5];
    snprintf(hexStr, sizeof(hexStr), "%04X", PowerData[index].VBUS_BUS);
    result += hexStr;
    snprintf(hexStr, sizeof(hexStr), "%04X", PowerData[index].VBUS_TOP);
    result += hexStr;
    snprintf(hexStr, sizeof(hexStr), "%04X", PowerData[index].VBUS_BOT);
    result += hexStr;
    snprintf(hexStr, sizeof(hexStr), "%04X", PowerData[index].VSHUNT_BUS);
    result += hexStr;
    snprintf(hexStr, sizeof(hexStr), "%04X", PowerData[index].VSHUNT_TOP);
    result += hexStr;
    snprintf(hexStr, sizeof(hexStr), "%04X", PowerData[index].VSHUNT_BOT);
    result += hexStr;
  }
  return result;
}

void setup() {
  Serial.begin(115200);

  Wire.begin(SDA, SCL);
  Serial.println("I2C Inited");

  initINA3221();
  Serial.println("Power Sensor Inited");

  pinMode(LED, OUTPUT);
  digitalWrite(LED, HIGH);

  Serial.println("IND Inited");

  ledcAttach(M1A, 50000, 8);
  ledcAttach(M1B, 50000, 8);
  ledcAttach(M2A, 50000, 8);
  ledcAttach(M2B, 50000, 8);
  Serial.println("LEDC Inited");

  pinMode(VBAT, INPUT);
  Serial.println("ADC Inited");
  attachInterrupt(M1EA, isr, CHANGE);
  attachInterrupt(M1EB, isr, CHANGE);
  attachInterrupt(M2EA, isr, CHANGE);
  attachInterrupt(M2EB, isr, CHANGE);
  Serial.println("Encoder Interrupt Inited");
  pinMode(M1EA, INPUT_PULLUP);
  pinMode(M1EB, INPUT_PULLUP);
  pinMode(M2EA, INPUT_PULLUP);
  pinMode(M2EB, INPUT_PULLUP);
  Serial.println("Encoder Inited");

  M1_rec = (digitalRead(M1EA) << 1) | digitalRead(M1EB);
  M2_rec = (digitalRead(M2EA) << 1) | digitalRead(M2EB);

  M1_PID.SetMode(AUTOMATIC);
  M2_PID.SetMode(AUTOMATIC);
  M1_PID.SetOutputLimits(-9000, 9000);
  M2_PID.SetOutputLimits(-9000, 9000);
  M1_velocity_PID.SetMode(AUTOMATIC);
  M2_velocity_PID.SetMode(AUTOMATIC);
  M1_velocity_PID.SetOutputLimits(-255, 255);
  M2_velocity_PID.SetOutputLimits(-255, 255);
  Serial.println("PID Inited");

  delay(500);
  digitalWrite(LED, LOW);

  // Connect to Wi-Fi network with SSID and password
  Serial.print("Connecting to ");
  Serial.println(ssid);
  WiFi.begin(ssid, password);
  while (WiFi.status() != WL_CONNECTED) {
    delay(500);
    Serial.print(".");
    digitalWrite(LED, !digitalRead(LED));
  }
  // Print local IP address and start web server
  Serial.println("");
  Serial.println("WiFi connected.");
  Serial.print("IP address: ");
  Serial.println(WiFi.localIP());
  Serial.print("MAC address: ");
  Serial.println(WiFi.macAddress());
  server.begin();

  ArduinoOTA
    .onStart([]() {
      String type;
      if (ArduinoOTA.getCommand() == U_FLASH)
        type = "sketch";
      else  // U_SPIFFS
        type = "filesystem";

      // NOTE: if updating SPIFFS this would be the place to unmount SPIFFS using SPIFFS.end()
      Serial.println("Start updating " + type);
    })
    .onEnd([]() {
      Serial.println("\nEnd");
    })
    .onProgress([](unsigned int progress, unsigned int total) {
      Serial.printf("Progress: %u%%\r", (progress / (total / 100)));
      digitalWrite(LED, !digitalRead(LED));
    })
    .onError([](ota_error_t error) {
      Serial.printf("Error[%u]: ", error);
      if (error == OTA_AUTH_ERROR) Serial.println("Auth Failed");
      else if (error == OTA_BEGIN_ERROR) Serial.println("Begin Failed");
      else if (error == OTA_CONNECT_ERROR) Serial.println("Connect Failed");
      else if (error == OTA_RECEIVE_ERROR) Serial.println("Receive Failed");
      else if (error == OTA_END_ERROR) Serial.println("End Failed");
    });

  ArduinoOTA.begin();
  Serial.println("OTA Inited");
  digitalWrite(LED, LOW);
}
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

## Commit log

2025-12-14 Rename Control Program Dolphin-- Current using.ipynb to Control_Program_Dolphin.ipynb
2025-12-14 Source and production files
    [BOM_Dolphin_Controller_PCB.xlsx, BOM_Dolphin_Encoder_PCB.xlsx, BOM_Dolphin_Main Board_PCB.xlsx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]
2025-12-14 Enhance PCB README with manufacturing and assembly info
    Updated PCB README with detailed manufacturing parameters and assembly components.
2025-12-14 Update screw specifications in README.md
